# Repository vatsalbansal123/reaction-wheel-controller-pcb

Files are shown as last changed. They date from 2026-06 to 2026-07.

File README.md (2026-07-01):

# Reaction Wheel BLDC Motor Control PCB

A compact, single-board controller for a brushless DC (BLDC) reaction wheel.

### Board at a glance

| | |
|---|---|
| **MCU** | STM32G431CBTx (Cortex-M4F, LQFP-48) |
| **Gate driver** | DRV8311H three-phase BLDC driver |
| **Communication** | CAN (SN65HVD231) + USB 2.0 (USB-C) |
| **Power input** | USB-C 5 V and screw-terminal motor supply |
| **Layers** | 2-layer copper (F.Cu / B.Cu) |
| **Outline** | ~48.6 × 49.5 mm, rounded corners (R2.5), four M2 corner mounting holes (H1–H4) |
| **Designed with** | KiCad 10 |

## Schematic

Schematic

## PCB

| Top | Bottom |
|-----|---|
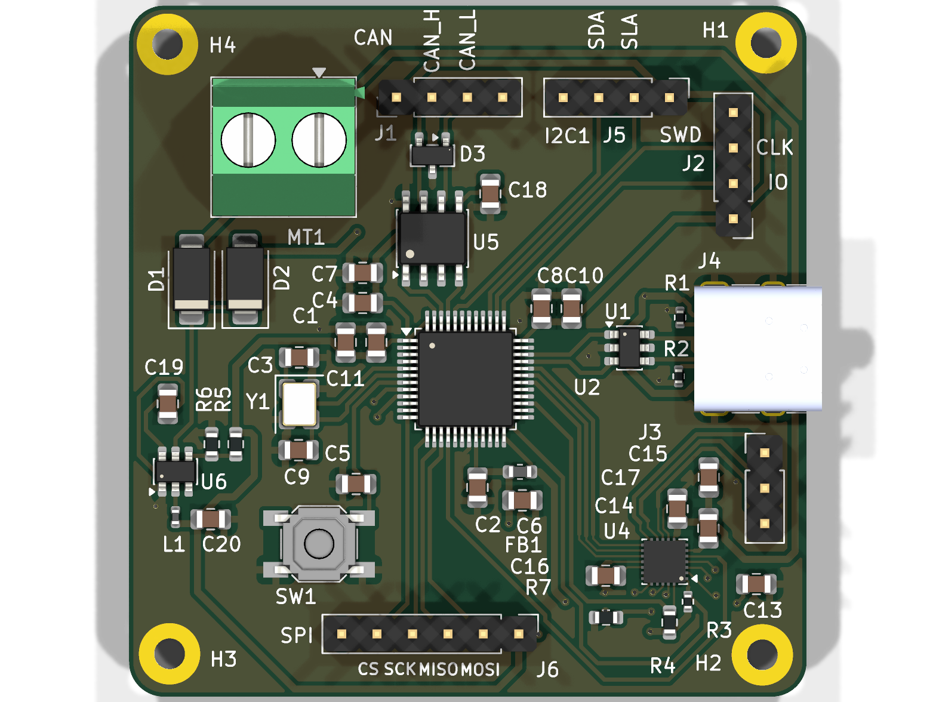
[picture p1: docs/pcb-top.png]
PCB top view
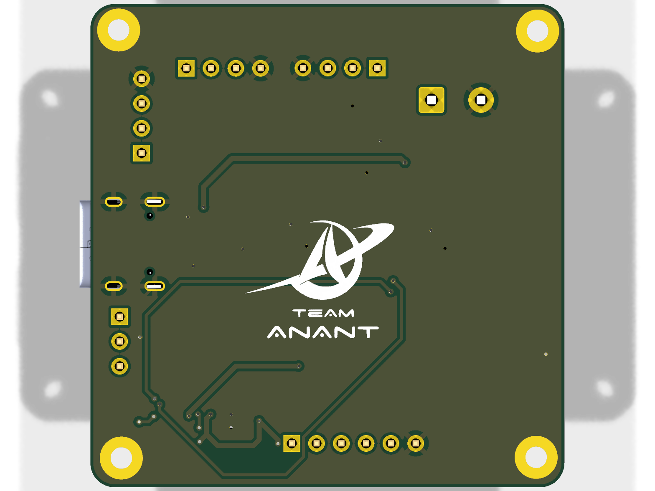
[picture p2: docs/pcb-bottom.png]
PCB bottom view
|  |  |

## Key Components

| Reference | Part | Function |
|---|---|---|
| U2 | STM32G431CBTx | Cortex-M4 motor-control MCU (LQFP-48) |
| U4 | DRV8311H | Three-phase BLDC gate driver / motor driver |
| U3 | AS5047D | Magnetic rotary position (angle) sensor |
| U5 | SN65HVD231 | CAN transceiver |
| U6 | TPS562200 | Step-down (buck) converter |
| U1 | USBLC6-2SC6 | USB ESD protection |
| D3 | NUP2105L | CAN bus ESD protection |
| Y1 | 16 MHz crystal | MCU clock source |
| J4 | USB-C receptacle | Power + USB 2.0 data |
| MT1 | Phoenix screw terminal | Motor power input |

### Connectors & I/O

- **J4** — USB-C (USB 2.0 + power)
- **MT1** — 2-pin screw terminal (motor phases / power)
- **J1** — 1x4 header, CAN (CAN_H / CAN_L)
- **J5** — 1x4 header, I²C (SDA / SCL)
- **J2** — 1x4 header, SWD debug (CLK / IO)
- **J6** — 1x6 header, SPI (CS / SCK / MISO / MOSI)
- **J3** — 1x3 pin header
- **SW1** — SPST tactile button

### Passives & Discretes

- **Capacitors:** 10n, 10p, 100n, 0.1u, 1u, 4.7u, 10u, 22u (0805 SMD)
- **Inductors:** 2.2u (0402), 120R ferrite bead (FB1)
- **Resistors:** 5k1, 10k, 30.1k, 47k, 100k (0402 / 0603 SMD)
- **Diodes:** SS34 Schottky (D1, D2)

> A full bill of materials can be regenerated from the schematic with:
> ```
> kicad-cli sch export bom reaction-wheel-bldc-motor-control-pcb.kicad_sch -o bom.csv
> ```

## Design Files

- `reaction-wheel-bldc-motor-control-pcb.kicad_sch` — schematic
- `reaction-wheel-bldc-motor-control-pcb.kicad_pcb` — PCB layout
- `reaction-wheel-bldc-motor-control-pcb.kicad_pro` — KiCad project

Designed with **KiCad 10**.

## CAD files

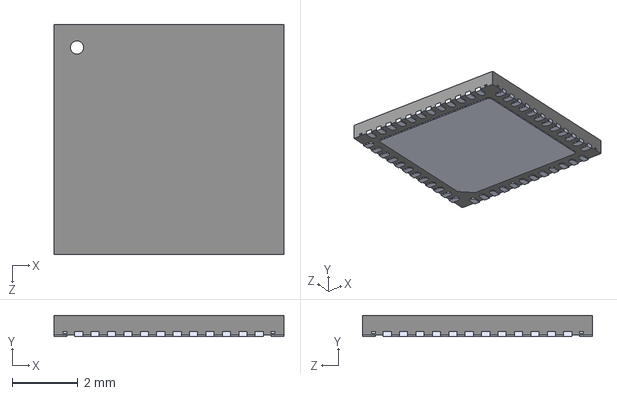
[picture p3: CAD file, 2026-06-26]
STM32G431CBU6.STEP
7.00 x 0.65 x 7.00 mm

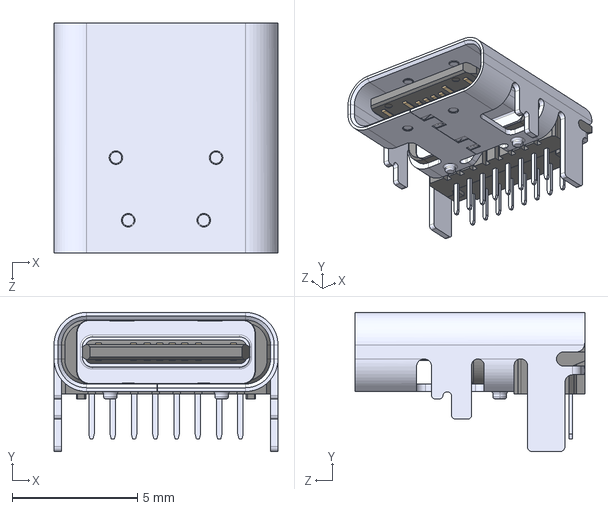
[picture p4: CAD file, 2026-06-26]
USB4085-GF-A--3DModel-STEP-56544.STEP
8.95 x 5.56 x 9.17 mm

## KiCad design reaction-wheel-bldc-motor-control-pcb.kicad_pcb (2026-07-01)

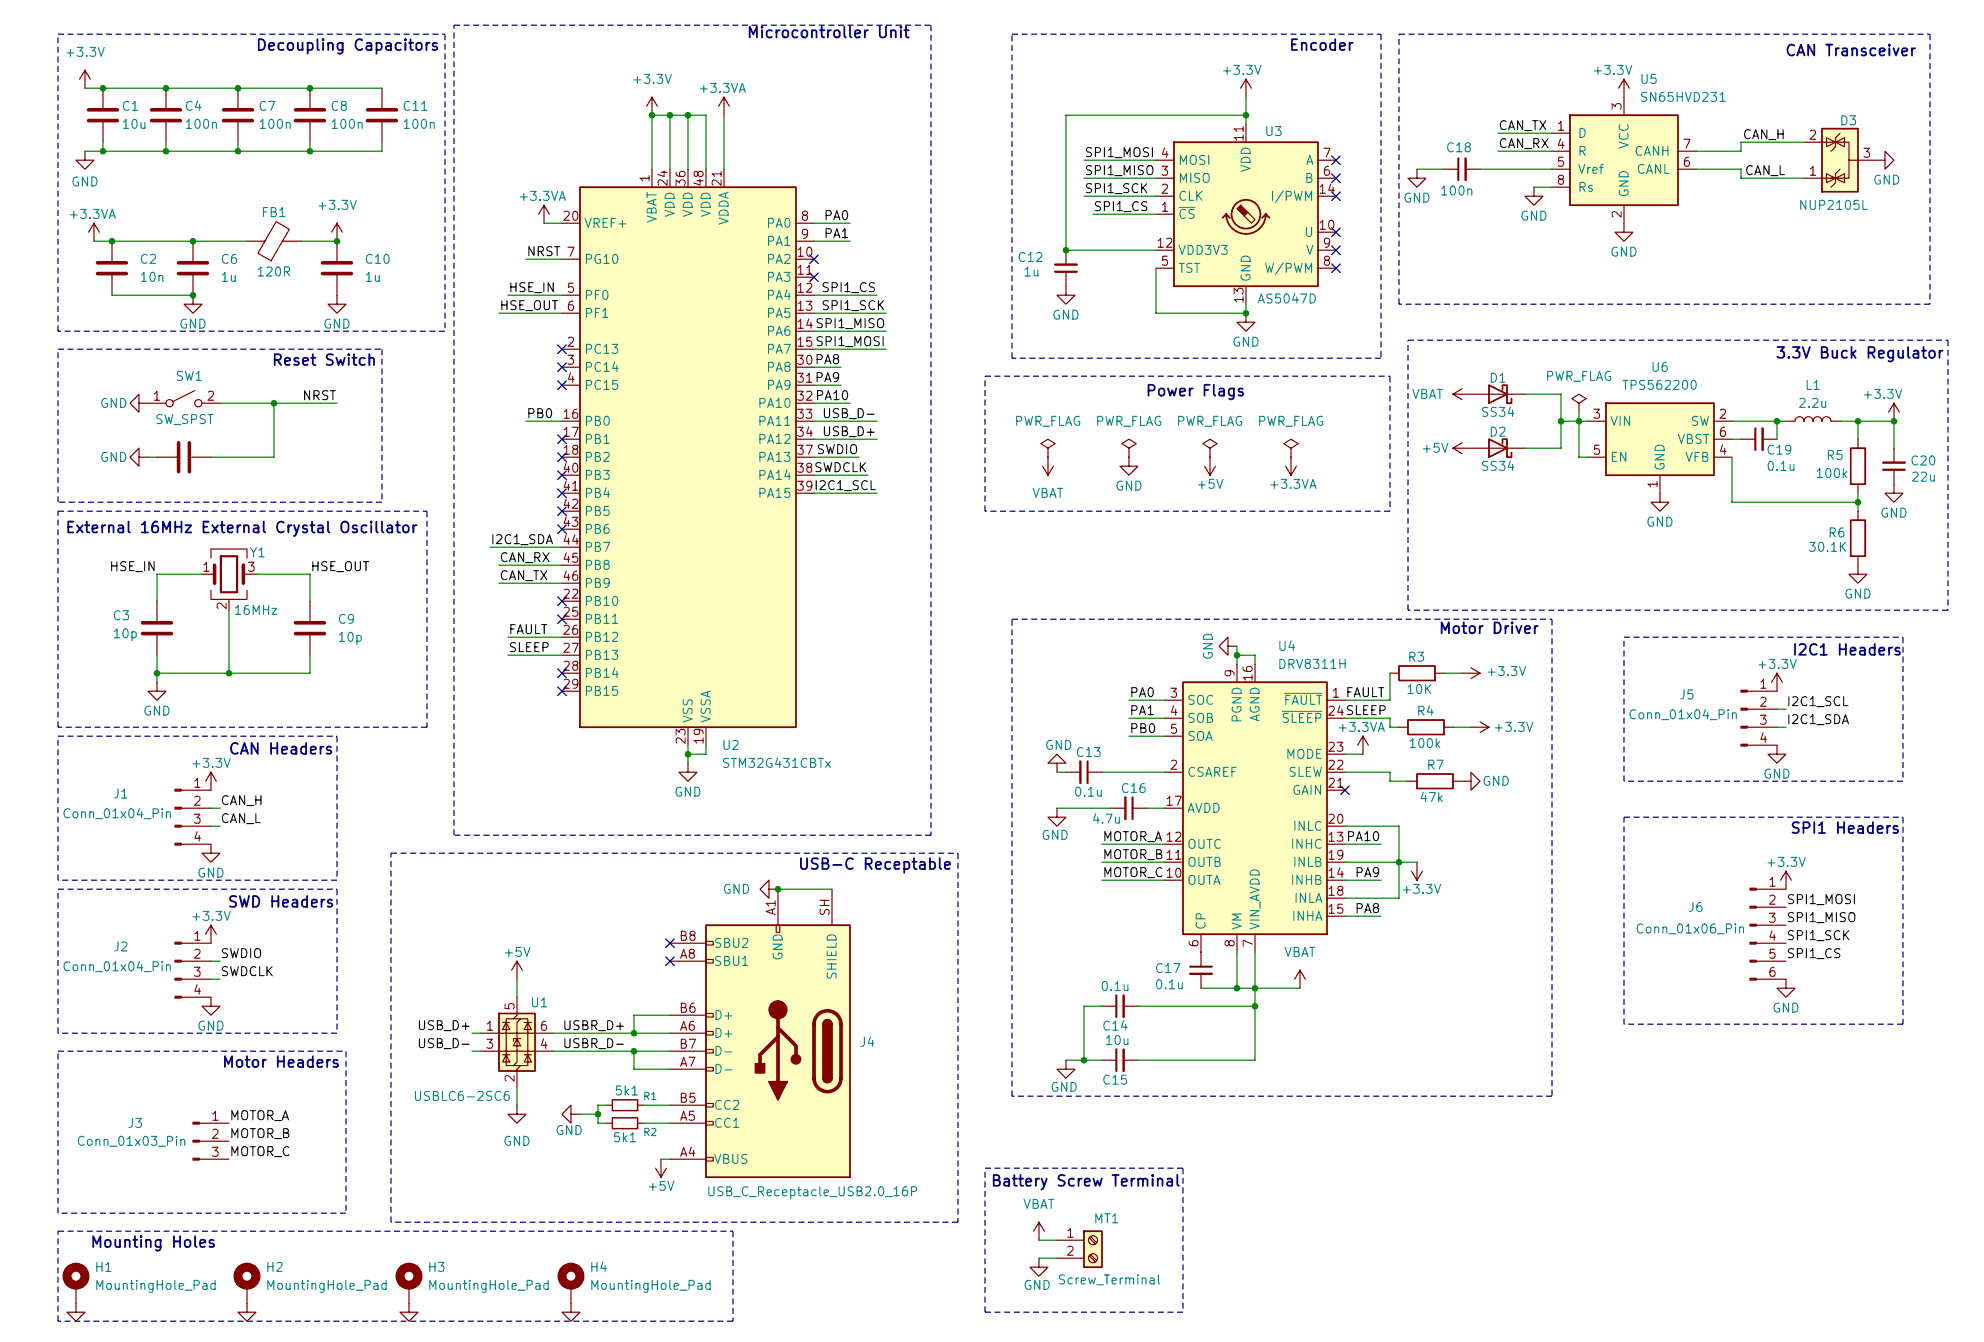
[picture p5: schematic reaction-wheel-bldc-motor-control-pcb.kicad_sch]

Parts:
C1, C15: 10u; C_0805_2012Metric
C2: 10n; C_0805_2012Metric
C3, C9: 10p; C_0805_2012Metric
C4, C7, C8, C11, C18: 100n; C_0805_2012Metric
C5, C13, C14, C17, C19: 0.1u; C_0805_2012Metric
C6, C10, C12: 1u; C_0805_2012Metric
C16: 4.7u; C_0805_2012Metric
C20: 22u; C_0805_2012Metric
D1, D2: SS34; D_SMA
D3: NUP2105L; SOT-23
FB1: 120R; L_0603_1608Metric
H1, H2, H3, H4: MountingHole_Pad; MountingHole_2.2mm_M2_Pad
J1, J2, J5: Conn_01x04_Pin; PinHeader_1x04_P2.54mm_Vertical
J3: Conn_01x03_Pin; PinHeader_1x03_P2.54mm_Vertical
J4: USB_C_Receptacle_USB2.0_16P; USB_C_Receptacle_G-Switch_GT-USB-7010ASV
J6: Conn_01x06_Pin; PinHeader_1x06_P2.54mm_Vertical
L1: 2.2u; L_0402_1005Metric
MT1: Screw_Terminal; TerminalBlock_Phoenix_MKDS-1,5-2-5.08_1x02_P5.08mm_Horizont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
R1, R2: 5k1; R_0402_1005Metric
R3: 10K; R_0402_1005Metric
R4, R5: 100k; R_0603_1608Metric
R6: 30.1K; R_0603_1608Metric
R7: 47k; R_0603_1608Metric
SW1: SW_SPST; SW_SPST_SKQG_WithStem
U1: USBLC6-2SC6; SOT-23-6
U2: STM32G431CBTx; LQFP-48_7x7mm_P0.5mm
U3: AS5047D; TSSOP-14_4.4x5mm_P0.65mm
U4: DRV8311H; Texas_RRW0024A_WQFN-24-1EP_3x3mm_P0.4mm_EP1.9x1.9mm
U5: SN65HVD231; SOIC-8_3.9x4.9mm_P1.27mm
U6: TPS562200; SOT-23-6
Y1: 16MHz; Crystal_SMD_3225-4Pin_3.2x2.5mm

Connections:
+3.3V: C1.1, C4.1, C7.1, C8.1, C10.1, C11.1, C12.2, C20.2, FB1.2, J1.1, J2.1, J5.1, J6.1, L1.2, R3.2, R4.2, R5.1, U2.1 (VBAT), U2.24 (VDD), U2.36 (VDD), U2.48 (VDD), U3.11 (VDD), U3.12 (VDD3V3), U4.18 (INLA), U4.19 (INLB), U4.20 (INLC), U5.3 (VCC)
+3.3VA: C2.1, C6.1, FB1.1, U2.20 (VREF+), U2.21 (VDDA), U4.23 (MODE)
+5V: D2.2 (A), J4.A4 (VBUS), J4.A9 (VBUS), J4.B4 (VBUS), J4.B9 (VBUS), U1.5 (VBUS)
/CAN_H: D3.2 (K), J1.2, U5.7 (CANH)
/CAN_L: D3.1 (K), J1.3, U5.6 (CANL)
/CAN_RX: U2.45 (PB8), U5.4 (R)
/CAN_TX: U2.46 (PB9), U5.1 (D)
/FAULT: R3.1, U2.26 (PB12), U4.1 (~FAULT)
/HSE_IN: C3.1, U2.5 (PF0), Y1.1
/HSE_OUT: C9.1, U2.6 (PF1), Y1.3
/I2C1_SCL: J5.2, U2.39 (PA15)
/I2C1_SDA: J5.3, U2.44 (PB7)
/MOTOR_A: J3.1, U4.12 (OUTC)
/MOTOR_B: J3.2, U4.11 (OUTB)
/MOTOR_C: J3.3, U4.10 (OUTA)
/NRST: C5.2, SW1.2 (B), U2.7 (PG10)
/PA0: U2.8 (PA0), U4.3 (SOC)
/PA1: U2.9 (PA1), U4.4 (SOB)
/PA8: U2.30 (PA8), U4.15 (INHA)
/PA9: U2.31 (PA9), U4.14 (INHB)
/PA10: U2.32 (PA10), U4.13 (INHC)
/PB0: U2.16 (PB0), U4.5 (SOA)
/SLEEP: R4.1, U2.27 (PB13), U4.24 (~SLEEP)
/SPI1_CS: J6.5, U2.12 (PA4), U3.1 (~CS)
/SPI1_MISO: J6.3, U2.14 (PA6), U3.3 (MISO)
/SPI1_MOSI: J6.2, U2.15 (PA7), U3.4 (MOSI)
/SPI1_SCK: J6.4, U2.13 (PA5), U3.2 (CLK)
/SWDCLK: J2.3, U2.38 (PA14)
/SWDIO: J2.2, U2.37 (PA13)
/USBR_D+: J4.A6 (D+), J4.B6 (D+), U1.6 (I/O1)
/USBR_D-: J4.A7 (D-), J4.B7 (D-), U1.4 (I/O2)
/USB_D+: U1.1 (I/O1), U2.34 (PA12)
/USB_D-: U1.3 (I/O2), U2.33 (PA11)
GND: C1.2, C2.2, C3.2, C4.2, C5.1, C6.2, C7.2, C8.2, C9.2, C10.2, C11.2, C12.1, C13.2, C14.1, C15.1, C16.2, C18.1, C20.1, D3.3 (A), H1.1 (1_1), H2.1 (1_1), H3.1 (1_1), H4.1 (1_1), J1.4, J2.4, J4.A1 (GND), J4.A12 (GND), J4.B1 (GND), J4.B12 (GND), J4.SH (SHIELD), J5.4, J6.6, MT1.2, R1.2, R2.2, R6.2, R7.1, SW1.1 (A), U1.2 (GND), U2.19 (VSSA), U2.23 (VSS), U2.35 (VSS), U2.47 (VSS), U3.5 (TST), U3.13 (GND), U4.9 (PGND), U4.16 (AGND), U4.25 (PGND), U5.2 (GND), U5.8 (Rs), U6.1 (GND), Y1.2 (G), Y1.4 (G)
unnamed: D1.1 (K), D2.1 (K), U6.3 (VIN), U6.5 (EN)
unnamed: J4.A5 (CC1), R2.1
unnamed: J4.B5 (CC2), R1.1
unnamed: C16.1, U4.17 (AVDD)
unnamed: C17.1, U4.6 (CP)
unnamed: C13.1, U4.2 (CSAREF)
unnamed: R7.2, U4.22 (SLEW)
unnamed: C18.2, U5.5 (Vref)
unnamed: C19.2, L1.1, U6.2 (SW)
unnamed: C19.1, U6.6 (VBST)
unnamed: R5.2, R6.1, U6.4 (VFB)
VBAT: C14.2, C15.2, C17.2, D1.2 (A), MT1.1, U4.7 (VIN_AVDD), U4.8 (VM)

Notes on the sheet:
Microcontroller Unit
Power Flags
Motor Headers
Motor Driver
SPI1 Headers
External 16MHz External Crystal Oscillator
I2C1 Headers
Mounting Holes
Encoder
Reset Switch
Battery Screw Terminal
CAN Transceiver
SWD Headers
3.3V Buck Regulator
USB-C Receptable
CAN Headers
Decoupling Capacitors

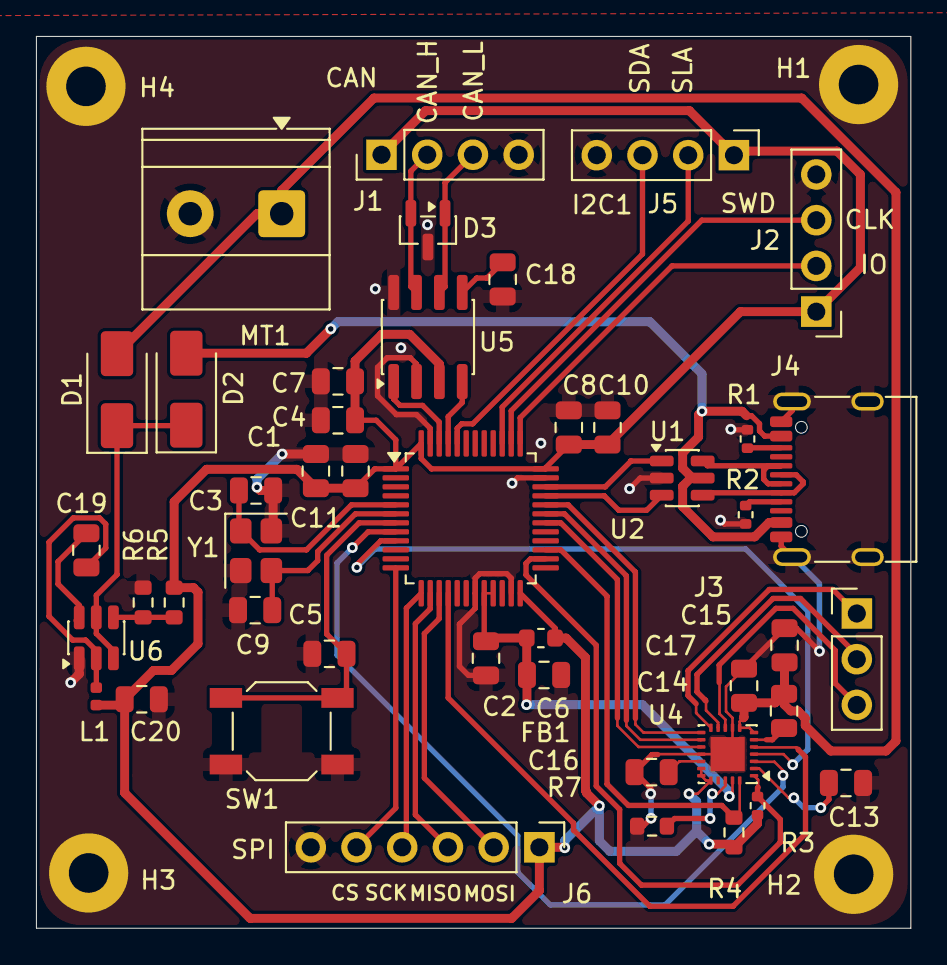
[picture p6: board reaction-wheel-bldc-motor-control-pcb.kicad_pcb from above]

Board: 2 copper layers, 48.6 x 49.5 mm, 49 parts (0 on the bottom side), 46 nets.

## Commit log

2026-06-18 schematic almost complete
    [reaction-wheel-bldc-motor-control-pcb.kicad_sch]
2026-06-23 started with pcb routing
    [reaction-wheel-bldc-motor-control-pcb.kicad_pcb, reaction-wheel-bldc-motor-control-pcb.kicad_sch]
2026-06-26 routing almost finished
    [STM32G431CBU6.STEP, USB4085-GF-A--3DModel-STEP-56544.STEP, reaction-wheel-bldc-motor-control-pcb.kicad_pcb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]
2026-06-29 fixed unrouted connections
    [reaction-wheel-bldc-motor-control-pcb.kicad_pcb]
2026-07-01 changed stm32 from u6 to t6
    [reaction-wheel-bldc-motor-control-pcb.kicad_pcb, reaction-wheel-bldc-motor-control-pcb.kicad_sch]
2026-07-01 complete drv8311 connections
    [reaction-wheel-bldc-motor-control-pcb.kicad_pcb, reaction-wheel-bldc-motor-control-pcb.kicad_sch]
